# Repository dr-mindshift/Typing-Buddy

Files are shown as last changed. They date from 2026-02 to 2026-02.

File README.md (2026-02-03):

# Typing Buddy: Feline-Integrated Input System

**Typing Buddy** is a hardware and software integration designed to allow a feline companion to interface with a computer system, enabling them to type in synchronization with the user. This project utilizes an Arduino-based mechanical rig and a background executable to bridge the gap between physical movement and digital input.

## System Overview

The system operates via a dual-layer architecture:

* **Hardware Layer:** An Arduino microcontroller manages the mechanical motor and key mechanisms.
* **Software Layer:** A Python script running on the host computer coordinates the interaction between user input and hardware response.

---

## 🛠 Preparation and Procurement

### 3D Printing Guidelines

Precision in the printing process is critical for the mechanical functionality of the system.

* **Base Accuracy:** Prioritize the accuracy of the base component; it is the foundation for the entire assembly.
* **Cat Paws/Arms:** Print with the paw pads on the bed (approx. 30° to 45° angle). This has been verified to print successfully on entry-level hardware like the Anycubic Kobra Neo.
* **ZERO INFILL:** It is mandatory to set the **infill to 0%** for the cat model. The internal volume must remain hollow to house the hardware.

### Equipment Acquisition

* **Bulk Sets:** Most components are sold in sets. The quantity of parts in standard sets makes it efficient to produce three units simultaneously.
* **Key Caps:** It is strongly recommended to purchase manufactured key caps. Attempting to 3D print caps and source individual keys is significantly more complex.

---

## 💻 Software Implementation

The project requires active code on both the Arduino and the host PC.

### 1. Arduino Configuration

* **Pin Assignments:** The code uses **Pin 9 and Pin 10** for motor speed and direction.
* **Customization:** Users can modify `run time` and `motor speed` variables at the start of the script.

### 2. Python Configuration

* **Communication Port:** Currently configured for **COM4**. Update this variable to match your Arduino's assigned port.
* **Baud Rate:** Set to **9600**.
* **System Augmentations:** Originally developed for integrated laptop keyboards. For USB-based external keyboards, you may need to run the script through an LLM (like Claude) for specific driver modifications.

### 3. Execution

* **Manual:** Initiate the script via PowerShell.
* **Automated:** Implement a `.bat` file in your startup folder to trigger the code automatically upon boot.

---

## 🔧 Mechanical Assembly and Modification

### Model Preparation

1. **Base Removal:** With **ZERO INFILL**, you can pull off the bottom layers of the cat print to leave the internal cavity open.
2. **Stomach Excavation:** Use a soldering iron to cut out the stomach section following the pre-designed indent. Remember: cut conservatively.
3. **Cable Pocket:** Use a soldering iron to cut a custom pocket where the Arduino USB cable exits for a more compact design.
4. **Aesthetics:** Facial features can be added manually using a permanent marker.

### Motor and Hinge Assembly

* **Floss Tie-Down:** Thread high-strength floss through the hole at the top of the motor. Pull it down into the cavity and tie it to the main structure. This prevents the motor from "pushing out" during use.
* **Hinge:** Insert a **16-gauge wire** through the arm holder to act as the dowel for the hinge mechanism.
* **Stabilization:** If the motor twists under torque, insert a secondary piece of 16-gauge wire (or use putty/glue) to lock it in place.

---

## ⚠️ Operational Notes

**The Escape Key "Kill Switch"**
The Escape key is programmed as the global termination command. If pressed, the script stops immediately and requires a manual restart. Users of CAD software should be especially mindful of this hardcoded functionality.

---

## 🔍 Troubleshooting

* **Scaling:** If parts do not mesh, minor scaling adjustments in your slicer may be necessary.
* **Motor Torque:** If the motor shifts clockwise/counter-clockwise, reinforce the tie-downs or use a 16-gauge wire brace.
* **Inconsistency:** Ensure the 16-gauge hinge wire moves freely and isn't snagging on the hollow cat shell.

## 🚀 System Augmentations

Users can further improve this model by:

* Developing a dedicated PCB to replace breadboard prototyping.
* Engineering a more compact design for the motor and key mechanisms.
* Optimizing structural holding materials for a smaller footprint.

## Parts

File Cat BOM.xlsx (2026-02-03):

Part | Purchase Link | Use in project/notes
Two Key Keychain | https://www.temu.com/2-key-fidget-keyboard-keychain-compatible-for-cherry---switches-switch-tester--relax-fidget-portable-typing-accessory-for--typists-switch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 | This is obviously for the cat to type on. This can be made personally with a 3d printer and two keys with caps.
L9110S DC Motor Drive Module | https://www.amazon.com/dp/B00M0F243E?ref=ppx_yo2ov_dt_b_fed_asin_title | This will be the voltage amplifier to make a concrete sepertation between arduino and motor feedback. In theory you could make this yourself with an H-Bridge. There are two motor ports, only one is needed for this projects.
Arduino Nano | https://www.amazon.com/dp/B0F6Y7GS4Q?ref=ppx_yo2ov_dt_b_fed_asin_title
Motor DC 3-6V Gearbox Motor | https://www.amazon.com/dp/B0BR7S2TRY?ref_=ppx_hzsearch_conn_dt_b_fed_asin_title_1&th=1 | You can in theory make this aswell but much easier to purchase online. This will drive the arms to click.
4 F2F Wires |  | These will connect the arduino to the Drive module.
Floss |  | Thit will hold the DC motor down to the system.
Firm wire |  | This will act as a dowel for the arms.

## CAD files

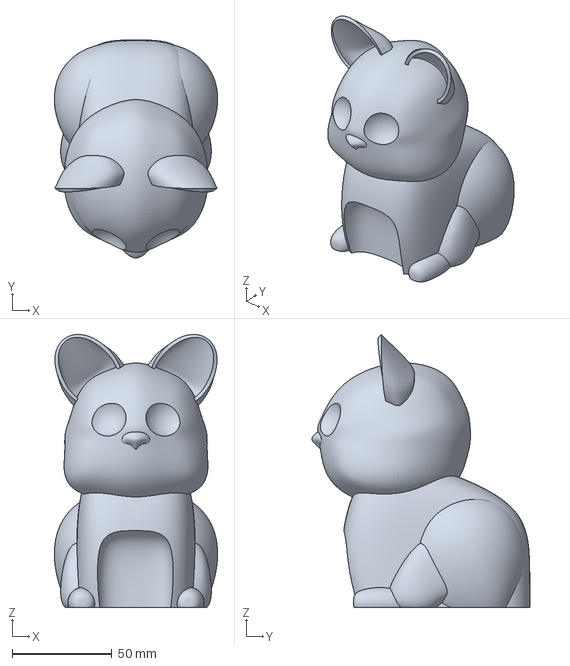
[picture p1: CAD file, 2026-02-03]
Cat_Final_Scaled.3mf
82.0 x 109.5 x 137.1 mm

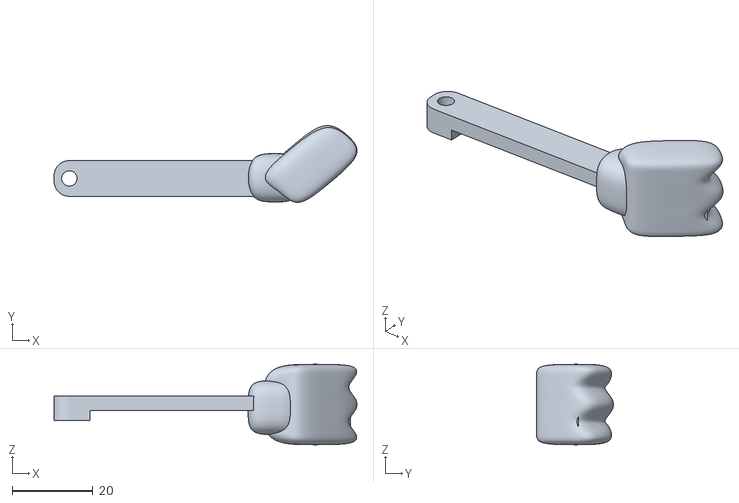
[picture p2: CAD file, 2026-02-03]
Left_Arm.stl
75.3 x 19.1 x 20.0

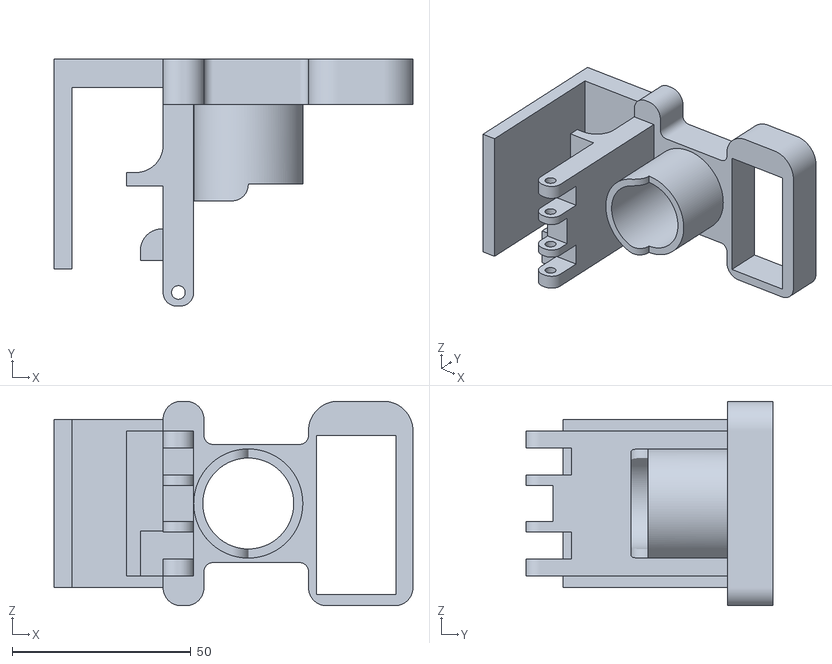
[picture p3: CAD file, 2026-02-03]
Cat_Holder_Structure.stl
100.3 x 69.1 x 57.2

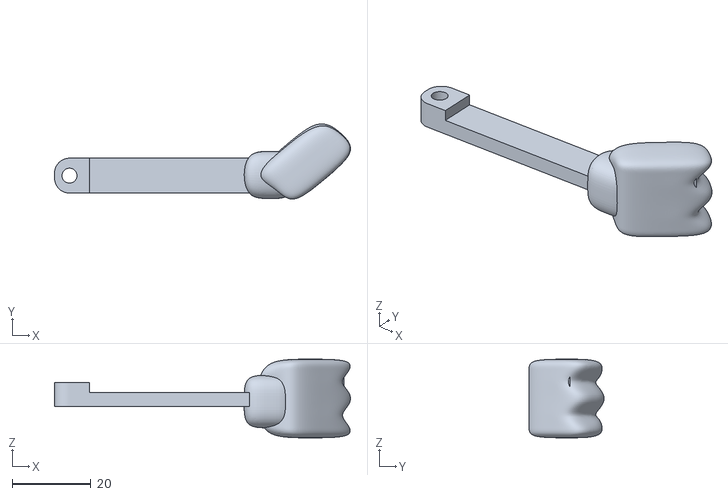
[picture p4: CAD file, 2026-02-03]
Right_Arm.stl
75.3 x 19.1 x 20.0

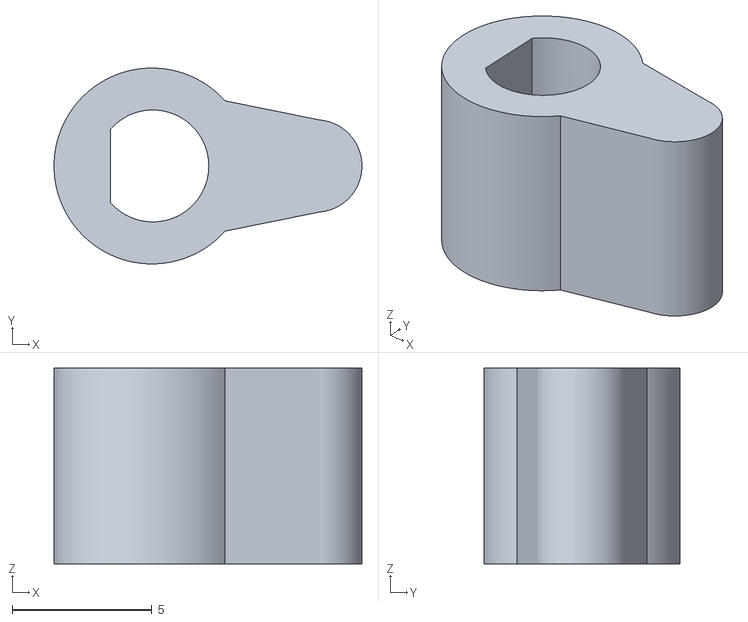
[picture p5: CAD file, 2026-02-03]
CAM_May_Need_Scaling.stl
11.0 x 7.00 x 7.00

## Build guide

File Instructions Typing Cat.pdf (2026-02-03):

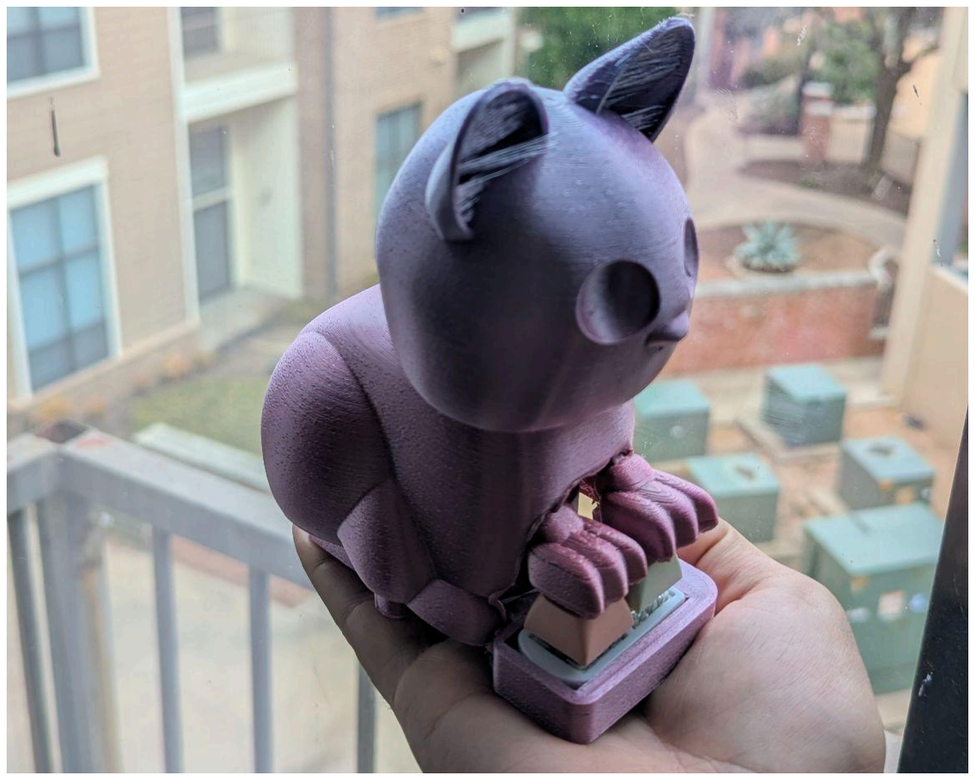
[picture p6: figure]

### 1. Preparation and Procurement

3D Printing Guidelines

The structural components must be printed with specific settings to ensure the internal mechanisms fit correctly.

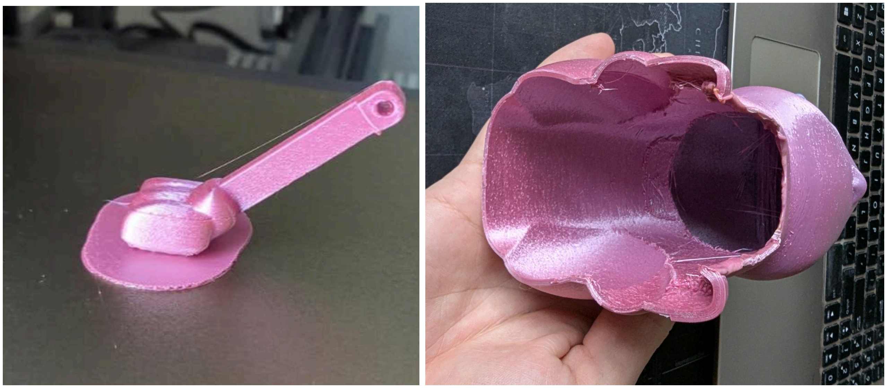
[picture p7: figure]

- Cat Paws/Arms: The paws should be oriented with the paw pads on the print bed. This creates an approximate 30° to 45° angle. These settings have been verified to print successfully on entry-level hardware, such as the Anycubic Kobra Neo.

## - Infill Requirements: It is mandatory to set the infill to 0% for

the cat model. Printing with any infill will render the project non-functional, as the internal volume must remain hollow for the hardware components.

Equipment Acquisition

- Bulk Purchasing: Most required components are sold in sets. While it is possible to build a single unit, the quantity of parts provided in standard sets makes it highly efficient to produce three units simultaneously.

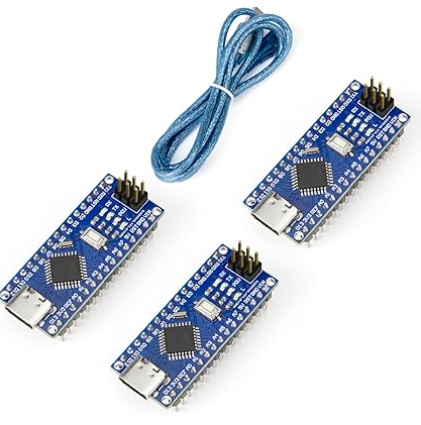
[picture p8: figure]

### 2. Software Implementation

This section details the requirements for the dual-layer code configuration. You must deploy two distinct files to synchronize the hardware with your computer's input.

Arduino Configuration (Microcontroller)

The Arduino handles the physical motor logic based on signals received from the computer.

- Pin Assignments: The code is configured to use Pin 9 and Pin 10 for controlling motor speed and direction.
- Variable Adjustments: Users can modify the run time and motor speed variables located at the beginning of the script to suit their specific mechanical resistance.

Python Configuration (Host Computer)

The Python script monitors keyboard activity and sends commands to the Arduino.

- Communication Port: The script is currently set to COM4. You must update this variable to match the specific port your Arduino is assigned to on your machine.
- Baud Rate: The data transfer rate is set to 9600. This can be adjusted if you are performing serial monitoring or testing before final implementation.
- System Customization: This code was originally developed for a laptop with an integrated keyboard. If you are using a USB-based external keyboard, the script may require minor modifications. It is recommended to use an LLM (such as Claude) to assist with these specific system augmentations.

### 3. Mechanical Assembly and Modification

This phase requires manual adjustments to the 3D-printed components to accommodate the internal hardware. These solutions are hobbyist-grade and prioritize functional integration over aesthetics.

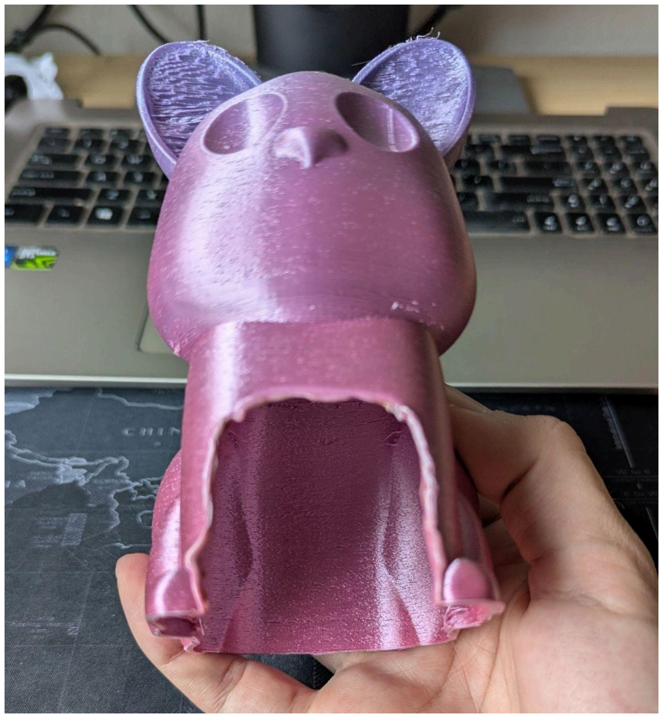
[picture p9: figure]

Model Preparation

The cat model must be modified to serve as a housing for the electronics.

- ZERO INFILL: It is imperative that the cat is printed with ZERO INFILL.
- Base Removal: Because the model is printed with no infill, you should be able to manually pull off the bottom layers of the print to leave the entire internal cavity hollow and open.
- Stomach Excavation: Using a soldering iron, cut out the stomach section of the cat. Follow the pre-designed indent on the model as a guide. It is recommended to cut conservatively; you can always remove more material later, but you cannot replace it.
- Cable Routing: Once the structure is assembled, identify where the Arduino USB cable exits. Use a soldering iron to cut a custom pocket in the cat’s shell for the cable to pass through, allowing for a more compact footprint.

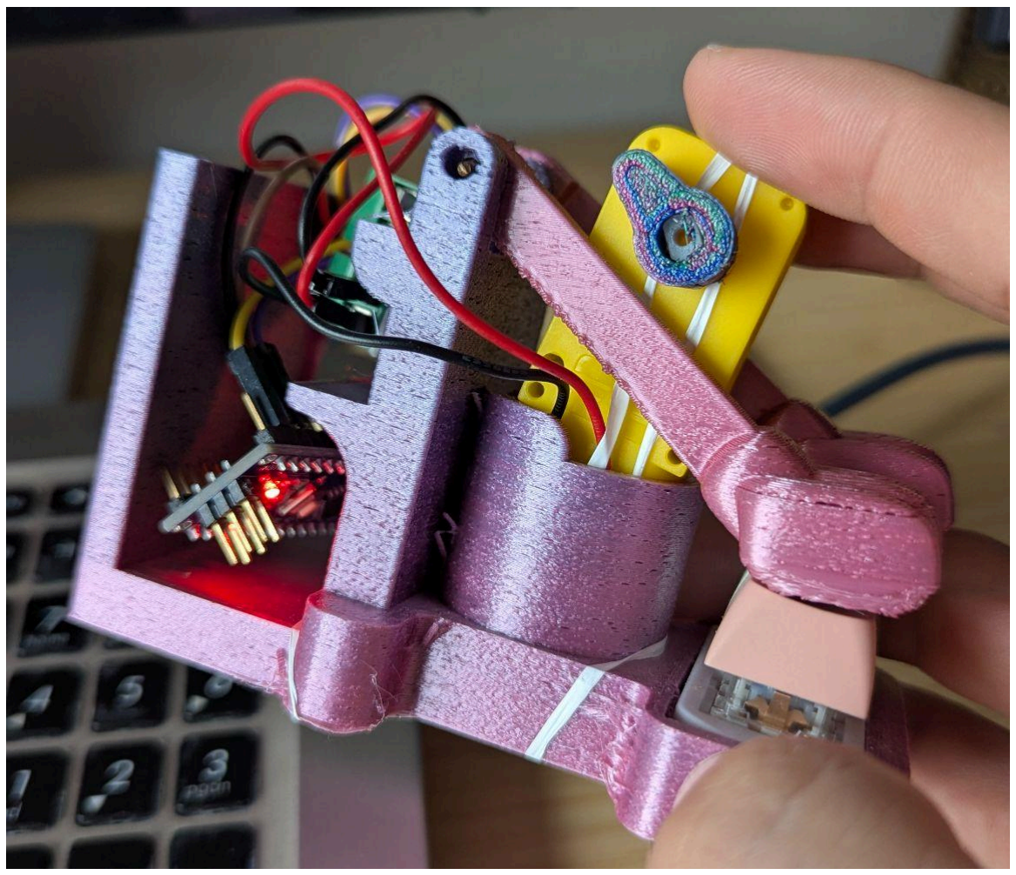
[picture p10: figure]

Motor Stabilization

During operation, the force of the keys typing creates upward pressure that can dislodge the motor from its housing.

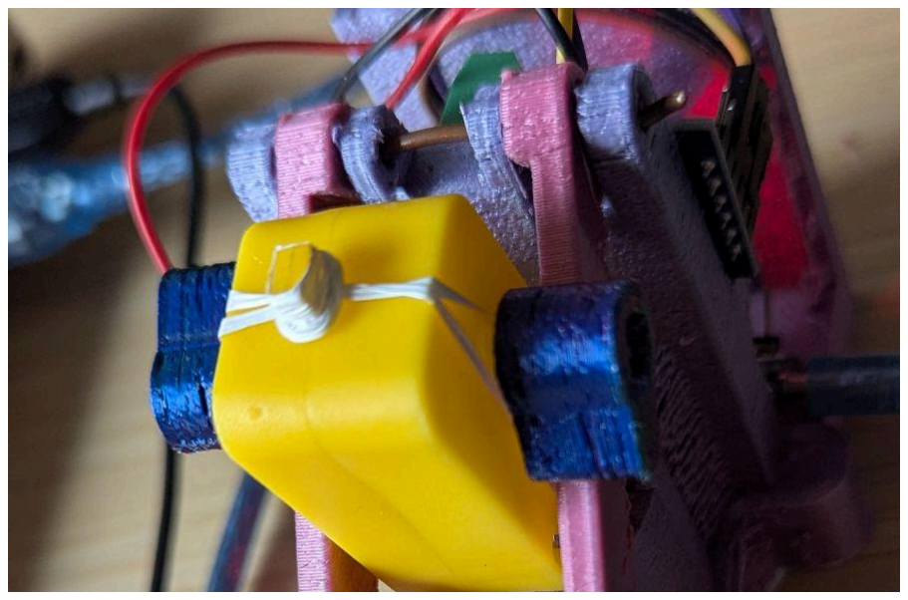
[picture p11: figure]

- Floss Tie-Down: To secure the motor, thread high-strength floss through the hole at the top of the motor. Pull the floss down into the motor cavity and tie it securely to the main structure.
- Range of Motion: This tie-down method prevents the motor from lifting out of the pocket while still allowing necessary side-to-side flex.
- Cam Adjustments: If you wish to reduce side-to-side swing, you may adjust the size of the cams. However, ensure the center bore of the cam remains compatible with the motor pegs; changing the internal diameter will prevent proper fitment.

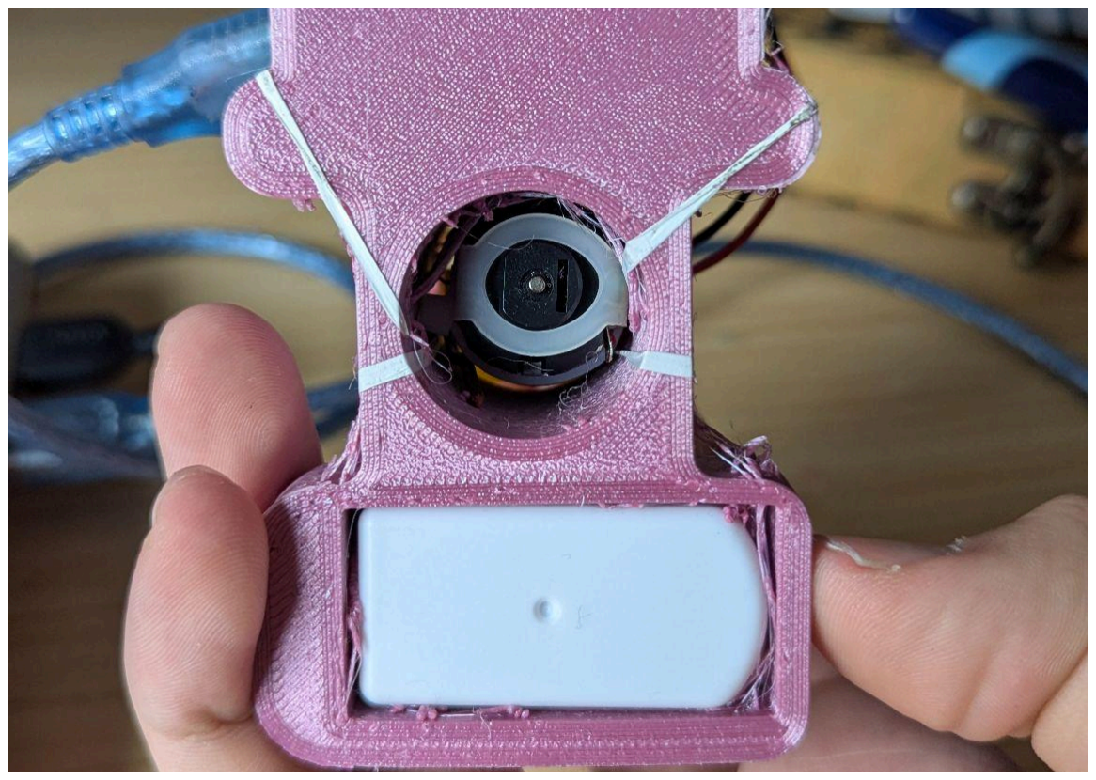
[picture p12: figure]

Final Integration

- Arm Hinge: The arms are connected to the main body using a hinge mechanism. Insert a 16-gauge wire through the arm holder to act as a dowel for the hinge.
- Wiring: Route the wires through the internal cavity toward the Arduino. Most remaining structural components are designed for a press-fit connection and do not require additional fasteners.

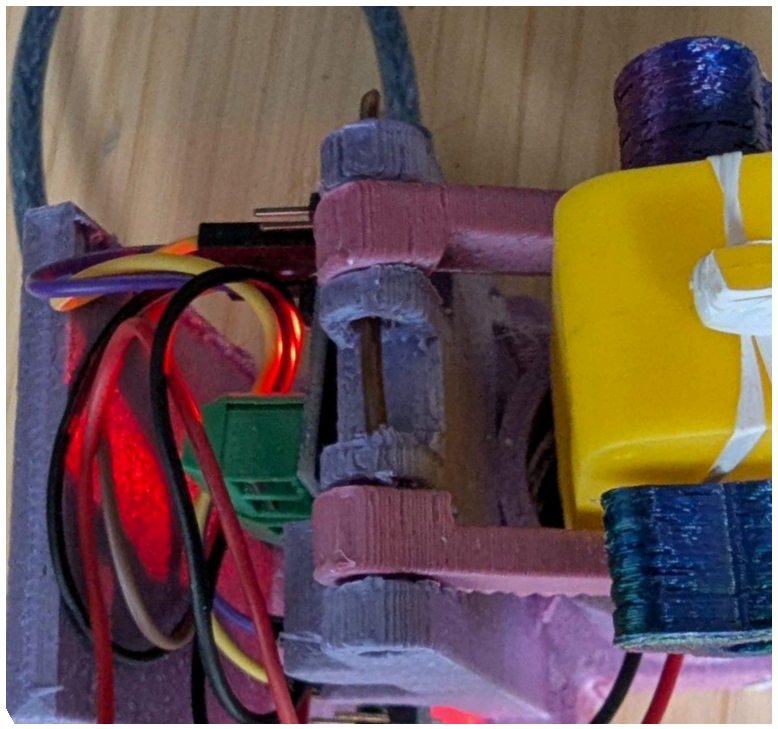
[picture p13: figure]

### 5. Troubleshooting

While the assembly is straightforward, the following points address common challenges encountered during development and testing.

Scaling and Dimensions

The files provided are intended to be scaled correctly for the internal hardware. However, due to variations in 3D printer tolerances:

- Fitment: If the components do not mesh correctly, minor scaling adjustments may be required in your slicer.
- Iterative Printing: Expect some trial and error with printing and re-printing to achieve the perfect fit for your specific motor and structural components.

Motor Stabilization and Torque

One of the primary challenges is the inconsistency of motor output caused by physical resistance. When pressure is applied to the keys, the motor tends to twist clockwise or counter-clockwise within its housing.

- Secondary Stabilization: To combat this twisting, a 16-gauge wire can be inserted into the side of the motor housing to provide additional lateral support.
- Alternative Adhesives: For a more permanent solution, hobbyists may use glue or mounting putty to further secure the motor against the torque generated during typing.

Support and Contact

This project is the result of significant testing and refinement. If you encounter issues not covered in this guide or have specific questions regarding the assembly of your Typing Buddy:

- Reach Out: Feel free to contact the developer personally for assistance. I will do my best to help you troubleshoot your specific system and hardware configuration.

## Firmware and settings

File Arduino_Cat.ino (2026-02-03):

// L9110S Motor Driver with Arduino
// Motor A connections
const int motorA_IA = 9;  // Speed control (PWM pin)
const int motorA_IB = 10; // Direction control (PWM pin)

// Motor run duration in milliseconds
const unsigned long RUN_DURATION = 300; // 2 seconds - adjust as needed

// Motor speed (0-255)
const int MOTOR_SPEED = 250; // Adjust speed here (0-255)

unsigned long motorStartTime = 0;
bool motorRunning = false;

void setup() {
  // Initialize serial communication
  Serial.begin(9600);
  
  // Set motor control pins as outputs
  pinMode(motorA_IA, OUTPUT);
  pinMode(motorA_IB, OUTPUT);
  
  // Make sure motor is stopped initially
  stopMotor();
  
  Serial.println("Arduino Ready!");
  Serial.println("Waiting for keyboard input...");
}

void loop() {
  // Check if data is available from serial
  if (Serial.available() > 0) {
    char incomingByte = Serial.read();
    
    // Any character received will trigger the motor
    Serial.print("Key pressed: ");
    Serial.println(incomingByte);
    
    // Start the motor
    startMotor();
  }
  
  // Check if motor should stop
  if (motorRunning && (millis() - motorStartTime >= RUN_DURATION)) {
    stopMotor();
    Serial.println("Motor stopped");
  }
}

void startMotor() {
  // Run motor forward
  analogWrite(motorA_IA, MOTOR_SPEED);
  analogWrite(motorA_IB, 0);
  
  motorStartTime = millis();
  motorRunning = true;
  
  Serial.println("Motor started");
}

void stopMotor() {
  // Stop the motor
  analogWrite(motorA_IA, 0);
  analogWrite(motorA_IB, 0);
  
  motorRunning = false;
}

// Alternative: To run motor in reverse, use this in startMotor():
// analogWrite(motorA_IA, 0);
// analogWrite(motorA_IB, MOTOR_SPEED);

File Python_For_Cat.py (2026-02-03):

import serial
from pynput import keyboard
import time

ARDUINO_PORT = 'COM4'
BAUD_RATE = 9600

ser = None

def on_press(key):
    """Called whenever a key is pressed"""
    try:
        # Only process keys that have a 'char' attribute (printable characters)
        if hasattr(key, 'char') and key.char:
            key_char = key.char
            print(f"Key pressed: {key_char}")
            
            # Send to Arduino
            if ser and ser.is_open:
                ser.write(key_char.encode())
                
                # Read response from Arduino
                time.sleep(0.05)
                while ser.in_waiting:
                    response = ser.readline().decode().strip()
                    if response:
                        print(f"Arduino: {response}")
        else:
            # Silently ignore special keys (backspace, ctrl, shift, etc.)
            pass
    
    except Exception as e:
        print(f"Error handling key: {e}")

def on_release(key):
    """Called when a key is released"""
    if key == keyboard.Key.esc:
        print("\nESC pressed - Exiting...")
        return False

def main():
    global ser
    
    print("Connecting to Arduino...")
    try:
        ser = serial.Serial(ARDUINO_PORT, BAUD_RATE, timeout=1)
        time.sleep(2)
        print(f"Connected to Arduino on {ARDUINO_PORT}")
        
        time.sleep(0.5)
        while ser.in_waiting:
            print(ser.readline().decode().strip())
        
        print("\n=== Motor Control Active ===")
        print("Press any key to activate motor")
        print("Press ESC to exit\n")
        
        with keyboard.Listener(on_press=on_press, on_release=on_release) as listener:
            listener.join()
        
        print("Keyboard listener stopped")
    
    except serial.SerialException as e:
        print(f"Error: Could not connect to Arduino on {ARDUINO_PORT}")
        print(f"Details: {e}")
    
    except Exception as e:
        print(f"Unexpected error: {e}")
    
    finally:
        if ser and ser.is_open:
            ser.close()
            print("Serial connection closed")

if __name__ == "__main__":
    main()
